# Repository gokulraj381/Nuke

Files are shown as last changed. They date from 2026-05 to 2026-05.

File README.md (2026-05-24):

# 🌱 Plant Buddy — Automated Plant Watering Bot

> A DIY automated plant watering system using ESP32-C3 SuperMini.  
> Monitors soil moisture, waters your plant automatically, shows status on OLED, and provides a Wi-Fi web dashboard for control.

**Anyone can build this!** Follow the step-by-step guide below.

---

## What Does It Do?

1. **Reads soil moisture** — sensor tells the ESP32 how dry/wet the soil is.
2. **Auto-waters** — when soil is too dry, the relay turns ON the pump for a short burst.
3. **Shows live data** — OLED screen displays moisture %, pump status, and Wi-Fi IP address.
4. **Web dashboard** — connect your phone to the ESP32's Wi-Fi and control everything from a browser.
5. **Manual button** — press a physical button to water immediately.
6. **Remembers settings** — calibration and thresholds are saved even after power-off.

---

## Project Photos

### Finished Build (3D-Printed Enclosure)
| Front (OLED + Button) | Inside (ESP32-C3 + Wiring) |
|:---:|:---:|
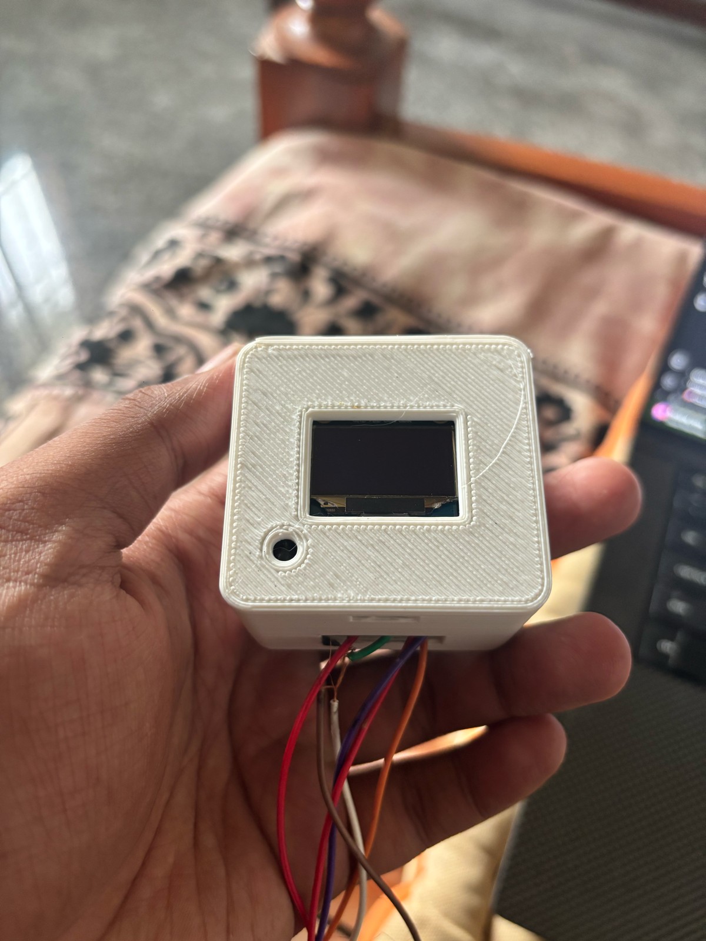
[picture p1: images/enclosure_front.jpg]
Enclosure Front
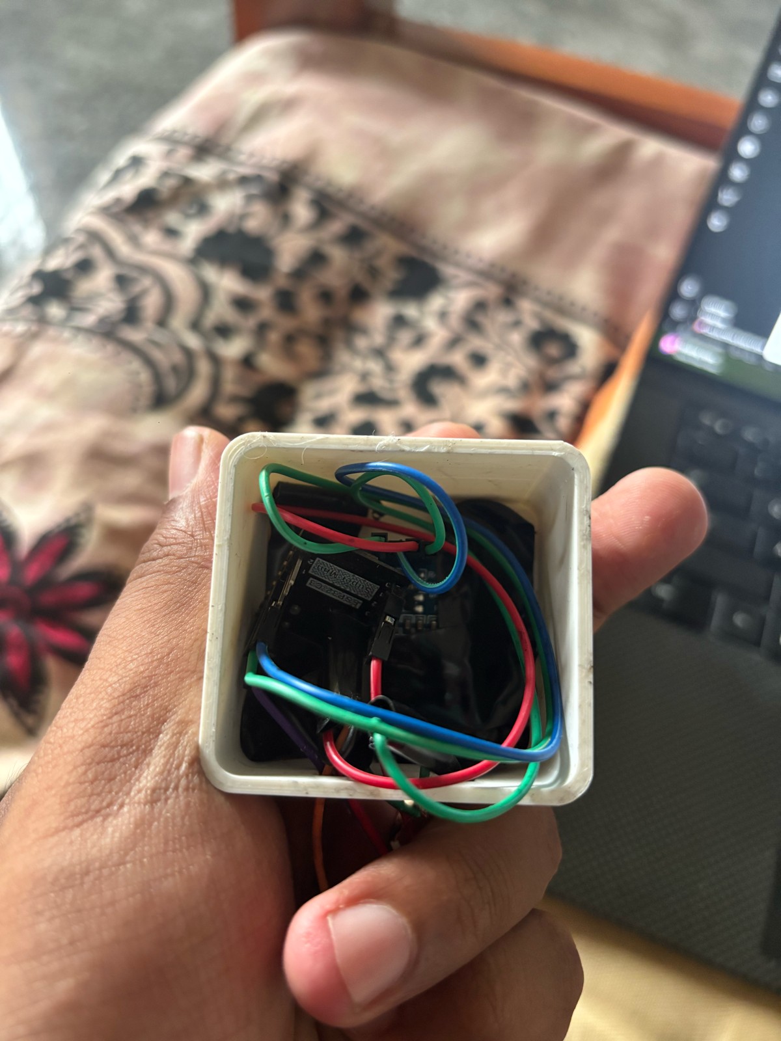
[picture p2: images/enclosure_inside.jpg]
Enclosure Inside
|  |  |

### Component Connections
| OLED Display | Soil Moisture Sensor | Relay Module |
|:---:|:---:|:---:|
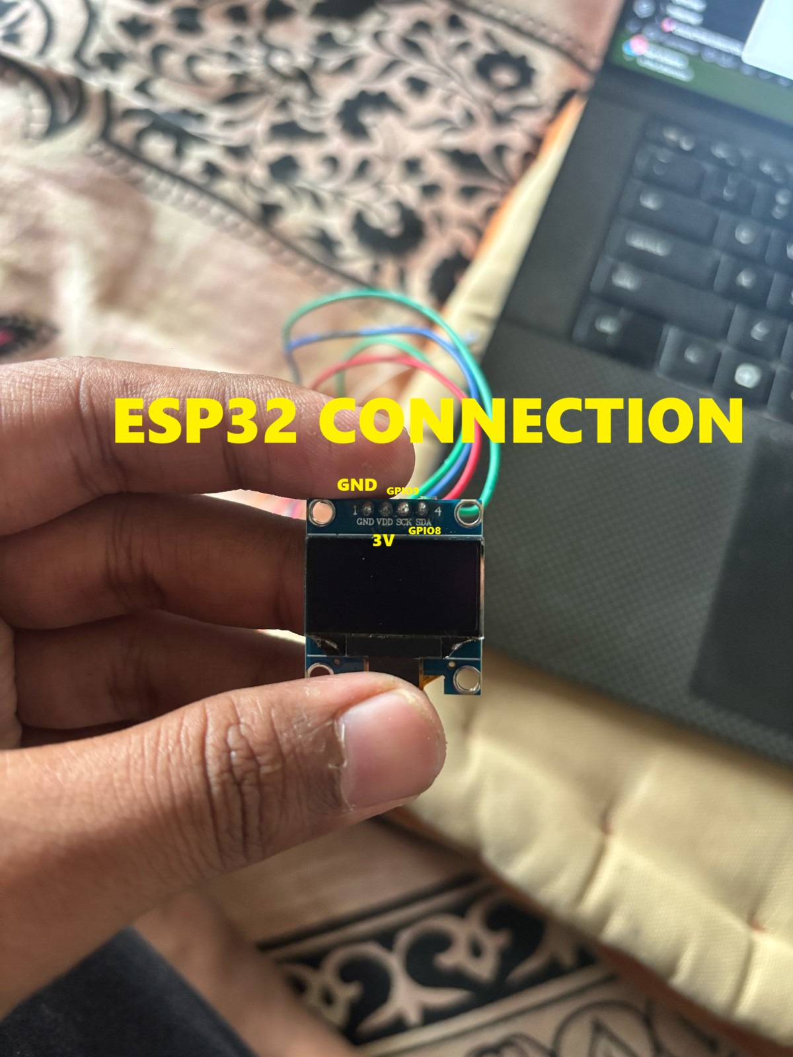
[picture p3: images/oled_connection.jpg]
OLED Connection
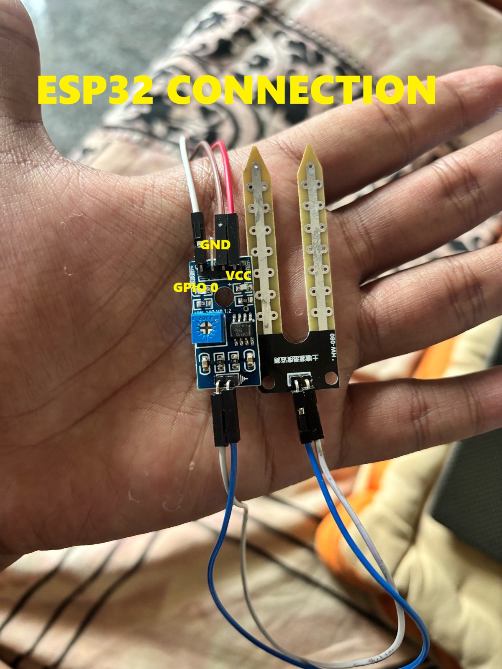
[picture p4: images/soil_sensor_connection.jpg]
Soil Sensor Connection
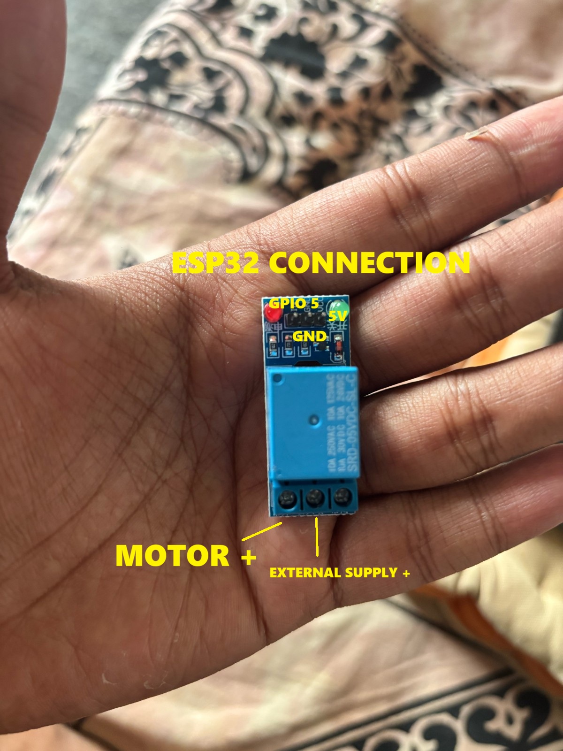
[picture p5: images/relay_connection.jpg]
Relay Connection
|  |  |  |

---

## Step-by-Step Build Guide

### Step 1: Understand the System

```
┌─────────────────────────────────────────────────────────────────────────┐
│                                                                         │
│   [Soil Sensor] ──analog──► [ESP32-C3] ──GPIO5──► [Relay] ──► [Pump]   │
│                                 │                                       │
│                            [OLED Screen]                                │
│                            [Button]                                     │
│                            [Wi-Fi Dashboard]                            │
│                                                                         │
└─────────────────────────────────────────────────────────────────────────┘
```

**How it works:**
- The soil sensor outputs an analog voltage (low = wet, high = dry).
- ESP32 reads it, calculates moisture %, and decides if watering is needed.
- If soil is dry → ESP32 sends LOW signal to relay → relay closes → pump runs.
- OLED + web dashboard show real-time info.

---

### Step 2: Pin Connections (IMPORTANT — Follow Exactly)

#### ESP32-C3 SuperMini Pin Map

| ESP32 Pin | Connects To | Wire Color (suggested) | Purpose |
|---|---|---|---|
| **GPIO0** | Soil sensor AO (analog out) | Blue | Read moisture level |
| **GPIO4** | Push button (other leg to GND) | Yellow | Manual water trigger |
| **GPIO5** | Relay IN pin | Green | Control pump ON/OFF |
| **GPIO8** | OLED SDA pin | Blue/White | OLED data |
| **GPIO9** | OLED SCL pin | Green/White | OLED clock |
| **3.3V** | OLED VCC + Soil sensor VCC | Red | Power to sensors |
| **5V** | Relay VCC | Red | Power to relay module |
| **GND** | OLED GND + Sensor GND + Relay GND + Button | Black | Common ground |

---

### Step 3: Wire the OLED Display

```
OLED Module          ESP32-C3 SuperMini
──────────           ──────────────────
   GND   ──────────►  GND
   VCC   ──────────►  3.3V  (or 3V pin)
   SCL   ──────────►  GPIO9
   SDA   ──────────►  GPIO8
```

> **Tip:** The OLED has 4 pins. Match GND-VCC-SCL-SDA carefully. Wrong VCC/GND will NOT damage it but nothing will display.

---

### Step 4: Wire the Soil Moisture Sensor

```
Soil Sensor Board    ESP32-C3 SuperMini
─────────────────    ──────────────────
   GND   ──────────►  GND
   VCC   ──────────►  3.3V
   AO    ──────────►  GPIO0  (analog output)
```

> **Note:** Use the **AO** (analog) pin, NOT the DO (digital) pin.  
> The sensor also has a separate 2-pin connector going to the fork probes — just plug that in.

---

### Step 5: Wire the Relay Module (Controls the Pump)

```
Relay Module         ESP32-C3 SuperMini
────────────         ──────────────────
   IN    ──────────►  GPIO5
   GND   ──────────►  GND
   VCC   ──────────►  5V

Relay Screw Terminals (high-voltage side):
   COM   ──────────►  Pump (+) wire
   NO    ──────────►  External 5V supply (+)

Pump (-) wire ──────► External 5V supply GND
                      External supply GND ──► ESP32 GND (MUST share ground)
```

**How the relay works:**
- When GPIO5 = HIGH → Relay OFF → Pump stops
- When GPIO5 = LOW → Relay ON → Pump runs
- The relay acts as a switch between your pump and the 5V power supply

> ⚠️ **NEVER** connect the pump directly to ESP32 pins. The pump draws too much current and will kill the chip.

---

### Step 6: Wire the Manual Button

```
Push Button          ESP32-C3 SuperMini
───────────          ──────────────────
   Leg 1  ──────────►  GPIO4
   Leg 2  ──────────►  GND
```

> **That's it!** The firmware uses internal pull-up. When you press the button, it connects GPIO4 to GND, which triggers a manual watering cycle.

---

### Step 7: Power Everything

**Option A: Single USB cable (recommended for testing)**
- Plug USB-C into the ESP32-C3 SuperMini
- This powers the ESP32 + OLED + Sensor
- For the pump, you need a separate 5V supply to the relay screw terminals

**Option B: External 5V supply powers everything**
- Feed 5V to ESP32's 5V pin and to relay/pump
- Share GND across all components

> ⚠️ **The pump MUST have its own 5V supply.** Don't try to run the pump from the ESP32 USB port — it can't provide enough current.

---

### Step 8: Upload the Firmware

#### Prerequisites
1. Install [VS Code](https://code.visualstudio.com/)
2. Install the **PlatformIO** extension (search "PlatformIO IDE" in Extensions)

#### Upload Steps
1. Open this project folder in VS Code
2. Connect ESP32-C3 SuperMini via USB-C cable
3. Wait for PlatformIO to install dependencies (first time takes a minute)
4. Click the **→ (Upload)** button in the PlatformIO toolbar at the bottom
   - Or run in terminal: `pio run -t upload`
5. Click the **🔌 (Serial Monitor)** button to see output at 115200 baud

**If upload fails:**
- Hold the BOOT button on ESP32 while clicking Upload
- Make sure the USB cable supports data (some are charge-only)
- Install CP2102/CH340 USB drivers if your OS doesn't detect the board

---

### Step 9: Connect to the Dashboard

1. After upload, the OLED will show the device IP address
2. On your phone/laptop, connect to Wi-Fi:
   - **SSID:** `PlantBuddy-C3`
   - **Password:** `plantbuddy123`
3. Open a browser and go to the IP shown on OLED (usually `192.168.4.1`)
4. You'll see the web dashboard with live moisture data and controls

> **Optional:** To connect to your home Wi-Fi instead of AP mode, edit these lines in `src/main.cpp`:
> ```cpp
> static const char* WIFI_SSID = "YourWiFiName";
> static const char* WIFI_PASSWORD = "YourWiFiPassword";
> ```

---

### Step 10: Calibrate the Sensor (MUST DO)

Every soil sensor is slightly different. You need to tell the system what "dry" and "wet" look like for YOUR sensor.

1. Open the web dashboard
2. **Keep the sensor probe in AIR (completely dry)**
   - Click **"Set Dry"** button on dashboard
   - This saves the current ADC reading as the "dry" reference
3. **Put the sensor probe fully into WATER (or very wet soil)**
   - Click **"Set Wet"** button on dashboard
   - This saves the current ADC reading as the "wet" reference
4. Set your preferred thresholds:
   - **Low threshold** (default 35%) — pump starts when moisture drops below this
   - **Target threshold** (default 55%) — pump stops when moisture rises above this
5. Click **"Save Settings"** — values are stored permanently

---

## System Block Diagram (Detailed)

```
                         ┌──────────────────────────────────┐
                         │      ESP32-C3 SuperMini          │
                         │                                  │
   ┌─────────────┐      │  GPIO8 (SDA) ◄──── I2C ────►    │      ┌──────────────────┐
   │  1.3" OLED  │◄────►│  GPIO9 (SCL)                    │      │  Soil Moisture   │
   │  (SSD1306)  │      │                                  │◄─────│  Sensor (AO)     │
   │  128x64 I2C │      │  GPIO0 (ADC) ◄── Analog In      │      │  Analog Output   │
   └─────────────┘      │                                  │      └──────────────────┘
                         │  GPIO5 (OUT) ──► Relay IN         │
                         │                      │           │      ┌──────────────────┐
                         │                      ▼           │      │   5V Water Pump  │
                         │               ┌───────────┐      │      │                  │
                         │               │   RELAY   │──────┼─────►│  (via NO/COM)    │
                         │               └───────────┘      │      └──────────────────┘
                         │                                  │
   ┌─────────────┐      │  GPIO4 (IN_PULLUP) ◄── Button   │      ┌──────────────────┐
   │ Push Button │──────►│                                  │      │  External 5V PSU │
   │ (Manual)    │      │  GPIO1 (IN_PULLUP) ◄── Tank Sw  │──────│  (Pump Power)    │
   └─────────────┘      │                                  │      └──────────────────┘
                         │  Wi-Fi (AP/STA)                  │
   ┌─────────────┐      │      ▲                           │
   │  Phone/PC   │◄────►│      │ HTTP Web Dashboard        │
   │  Browser    │      │                                  │
   └─────────────┘      └──────────────────────────────────┘
```

---

## Dashboard Controls Explained

| Button | What It Does |
|---|---|
| **Water Now** | Immediately turns on pump for a short burst (manual watering) |
| **Toggle Auto** | Enable/disable automatic watering logic |
| **Set Dry** | Save current ADC reading as the "dry soil" calibration point |
| **Set Wet** | Save current ADC reading as the "wet soil" calibration point |
| **Save Settings** | Write all values to flash memory (survives reboot/power-off) |

**Live display shows:** Moisture %, raw ADC value, pump ON/OFF status, tank level (if connected)

---

## Settings Reference

| Setting | What It Means | Default |
|---|---|---|
| Dry ADC | ADC reading when sensor is in dry air | 4005 |
| Wet ADC | ADC reading when sensor is in water | 1921 |
| Low Threshold | Start watering when moisture drops below this % | 35% |
| Target Threshold | Stop watering when moisture rises above this % | 55% |
| Pump Run Time | How long pump runs per auto-water cycle | 700 ms |
| Cooldown | Minimum wait between auto-water cycles | 90 seconds |
| Manual Pump Time | How long pump runs when you press the button | 600 ms |

---

## Troubleshooting

| Problem | Solution |
|---|---|
| OLED blank | Check SDA/SCL wires. Try swapping them. Ensure OLED address is 0x3C |
| Moisture always 0% or 100% | Run calibration (Set Dry + Set Wet). Check AO wire to GPIO0 |
| Pump won't turn on | Check relay wiring. Ensure external 5V supply is connected. Check COM/NO terminals |
| Can't upload firmware | Hold BOOT button during upload. Try a different USB cable |
| Can't find Wi-Fi | Wait 10 seconds after power-on. SSID is `PlantBuddy-C3` |
| Dashboard not loading | Make sure you're connected to PlantBuddy Wi-Fi, then open `192.168.4.1` |
| Pump runs non-stop | Calibration is wrong — redo Set Dry / Set Wet. Check threshold values |

---

## Project Structure

```
plant-buddy/
├── platformio.ini              # Build config + library dependencies
├── README.md                   # This guide
├── images/                     # Photos of the build
├── cad/                        # 3D-printable enclosure files
│   ├── plantbuddy_back.scad    # Back cover (OpenSCAD source)
│   ├── plantbuddy_front.scad   # Front panel with OLED cutout
│   └── stl/                    # Ready-to-print STL files
└── src/
    └── main.cpp                # Complete firmware (single file)
```

---

## Optional: 3D-Printed Case

STL files are in the `cad/stl/` folder. Print with:
- Material: PLA or PETG
- Layer height: 0.2mm
- Infill: 20%
- No supports needed

The case has a cutout for the OLED display and a hole for the manual button.

---

## Optional: Tank Level Switch

If you want the system to stop watering when the water tank is empty:

1. In `src/main.cpp`, change: `static const bool USE_TANK_SENSOR = true;`
2. Connect a float switch between **GPIO1** and **GND**
3. When tank is empty, the switch opens → GPIO1 reads HIGH → pump won't run

---

## License

MIT — Free to use, modify, and share.

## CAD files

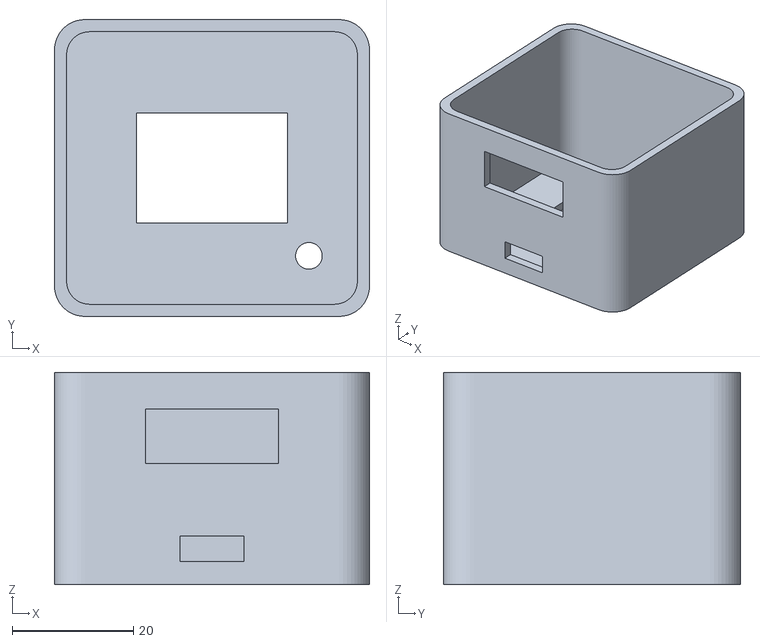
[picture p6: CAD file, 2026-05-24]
cad/stl/plantbuddy_front.stl
52.0 x 49.0 x 35.0

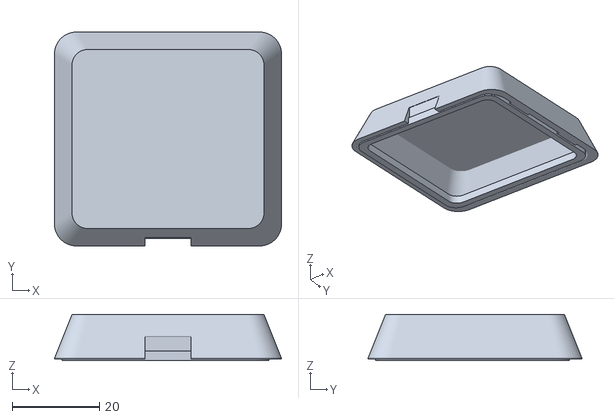
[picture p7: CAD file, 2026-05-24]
cad/stl/plantbuddy_back.stl
52.0 x 49.0 x 10.6

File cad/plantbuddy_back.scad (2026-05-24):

// Plant Buddy - Back Shell
// Nico-style rounded dome back with snap lip, vent slots, and cable exit.

$fn = 48;

wall = 2.0;
corner_r = 5;
lip_h = 2.2;
lip_inset = 0.30;
lip_shell_overlap_z = -0.4;
lip_shell_overlap_xy = 0.55;
eps = 0.2;

inner_w = 48.0;
inner_h = 45.0;

ext_w = inner_w + wall * 2;
ext_h = inner_h + wall * 2;

dome_h = 10.0;

usb_w = 10.5;
usb_h = 4.2;

module rounded_box(w, h, d, r) {
    hull() {
        for (x = [r, w - r])
            for (y = [r, h - r])
                translate([x, y, 0])
                    cylinder(r = r, h = d);
    }
}

module dome_back(w, h, rise) {
    hull() {
        rounded_box(w, h, 0.15, corner_r);
        translate([4, 4, rise])
            rounded_box(w - 8, h - 8, 0.15, corner_r - 1.4);
    }
}

difference() {
    // Outer skin.
    dome_back(ext_w, ext_h, dome_h);

    // Hollow interior shell.
    translate([wall, wall, -eps])
        dome_back(ext_w - wall * 2, ext_h - wall * 2, dome_h - wall + eps);

    // USB opening alignment.
    translate([ext_w / 2 - usb_w / 2, -0.1, -0.1])
        cube([usb_w, wall + 0.2, usb_h + 1.0]);

    // Ventilation slots near top.
    for (i = [0:4])
        translate([ext_w / 2 - 10 + i * 5, ext_h - wall - 0.1, dome_h - 2])
            rotate([-90, 0, 0])
                cylinder(r = 1.0, h = wall + 0.2);
}

// Snap-fit lip that goes inside the front shell.
translate([wall + lip_inset - lip_shell_overlap_xy, wall + lip_inset - lip_shell_overlap_xy, lip_shell_overlap_z])
difference() {
    rounded_box(inner_w - lip_inset * 2, inner_h - lip_inset * 2, lip_h, corner_r - 1.5);
    translate([wall, wall, -0.1])
        rounded_box(inner_w - lip_inset * 2 - wall * 2, inner_h - lip_inset * 2 - wall * 2, lip_h + 0.2, corner_r - 2.3);
}

// Bridge tabs that tie the lip to shell rim (prevents multi-volume STL export).
translate([wall - 0.2, wall + 8, 0]) cube([0.9, 8, 1.8]);
translate([wall - 0.2, ext_h - wall - 16, 0]) cube([0.9, 8, 1.8]);
translate([ext_w - wall - 0.7, wall + 8, 0]) cube([0.9, 8, 1.8]);
translate([ext_w - wall - 0.7, ext_h - wall - 16, 0]) cube([0.9, 8, 1.8]);

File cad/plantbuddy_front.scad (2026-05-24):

// Plant Buddy - Front Shell
// Nico-style rounded shell with two leaf ears, OLED window, and button hole.

$fn = 48;

// Core dimensions (mm)
wall = 2.0;
tol = 0.35;
corner_r = 5;

oled_module_w = 26.0;   // 2.6 cm OLED module width
oled_module_h = 30.0;   // 3.0 cm OLED module height
display_total_h = oled_module_h;
oled_glass_w = 25.0;    // 2.5 cm window width
oled_glass_h = 17.0;    // 1.7 cm window height

inner_w = 48.0;
inner_h = 45.0;
front_total_depth = 35.0; // 3.5 cm front-only depth (front to back)
inner_d = front_total_depth - wall;

ext_w = inner_w + wall * 2;
ext_h = inner_h + wall * 2;
ext_d = inner_d + wall;

usb_w = 10.5;
usb_h = 4.2;

button_r = 2.2;
eps = 0.2;

module rounded_box(w, h, d, r) {
    hull() {
        for (x = [r, w - r])
            for (y = [r, h - r])
                translate([x, y, 0])
                    cylinder(r = r, h = d);
    }
}

module leaf_ear(height, base_w, tip_shift, depth) {
    translate([0, 0, -depth / 2])
    linear_extrude(height = depth) {
        // Leaf silhouette kept solid to avoid split volumes.
        hull() {
            scale([1.0, 0.50]) circle(r = base_w / 2);
            translate([tip_shift * 0.45, height * 0.55])
                scale([0.75, 0.35]) circle(r = base_w / 2);
            translate([tip_shift, height])
                circle(r = 2.2);
        }
    }
}

difference() {
    union() {
        rounded_box(ext_w, ext_h, ext_d, corner_r);
    }

    // Main internal cavity.
    translate([wall, wall, wall - eps])
        rounded_box(inner_w, inner_h, ext_d + eps * 2, corner_r - 1.2);

    // OLED viewing window.
    oled_win_w = oled_glass_w;
    oled_win_h = oled_glass_h + 1.2;
    win_x = (ext_w - oled_win_w) / 2;
    win_y = (ext_h - display_total_h) / 2 + (display_total_h - oled_win_h) / 2;
    translate([win_x, win_y, -0.1])
        cube([oled_win_w, oled_win_h, wall + 0.2]);

    // USB-C opening (bottom edge).
    translate([ext_w / 2 - usb_w / 2, -0.1, wall + 1.8])
        cube([usb_w, wall + 0.2, usb_h]);

    // Right-side near-back wire hole (away from OLED side), support-free profile.
    right_back_hole_w = 21.0;
    right_back_hole_h = 6.0;
    right_back_hole_cy = ext_h - 12.0;
    right_back_hole_cz = ext_d - (wall + 4.2);
    translate([ext_w - 0.1, 0, 0])
        linear_extrude(height = wall + 0.2)
            polygon(points = [
                [right_back_hole_cy - right_back_hole_w / 2, right_back_hole_cz],
                [right_back_hole_cy, right_back_hole_cz + right_back_hole_h / 2],
                [right_back_hole_cy + right_back_hole_w / 2, right_back_hole_cz],
                [right_back_hole_cy, right_back_hole_cz - right_back_hole_h / 2]
            ]);

    // Large rectangular hole at marked front area (upper center of visible side).
    front_marked_hole_w = 22.0;
    front_marked_hole_h = 9.0;
    front_marked_hole_x = (ext_w - front_marked_hole_w) / 2;
    front_marked_hole_z = ext_d - 15.0;
    translate([front_marked_hole_x, -0.1, front_marked_hole_z])
        cube([front_marked_hole_w, wall + 0.2, front_marked_hole_h]);

    // Manual button hole near lower-right front.
    translate([ext_w - 10, 10, -0.1])
        cylinder(r = button_r, h = wall + 0.2);

}

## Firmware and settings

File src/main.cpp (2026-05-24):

#include <Arduino.h>
#include <Wire.h>
#include <Adafruit_GFX.h>
#include <Adafruit_SSD1306.h>
#include <WiFi.h>
#include <WebServer.h>
#include <Preferences.h>
#include <time.h>

// -------- OLED CONFIG --------
static const int SCREEN_WIDTH = 128;
static const int SCREEN_HEIGHT = 64;
static const int OLED_RESET = -1;
static const uint8_t OLED_ADDR = 0x3C;

// ESP32-C3 SuperMini common I2C pins (change if your board uses others)
static const int I2C_SDA_PIN = 8;
static const int I2C_SCL_PIN = 9;

// -------- PLANT SYSTEM PINS --------
// Moisture sensor analog output pin (ADC-capable). GPIO0 is common on ESP32-C3.
static const int SOIL_SENSOR_PIN = 0;

// Pump control pin. Drive a MOSFET/relay, never the pump directly.
static const int PUMP_PIN = 5;
static const bool RELAY_ACTIVE_LOW = true;

// Manual force-water button (connect button to GND and this pin).
static const int MANUAL_BUTTON_PIN = 4;

// Optional tank level switch (set to false if you do not use one).
static const bool USE_TANK_SENSOR = false;
static const int TANK_SENSOR_PIN = 1;

// -------- WIFI CONFIG --------
// Leave WIFI_SSID empty to run AP-only mode.
static const char* WIFI_SSID = "";
static const char* WIFI_PASSWORD = "";
static const char* AP_SSID = "PlantBuddy-C3";
static const char* AP_PASSWORD = "plantbuddy123";

// -------- CALIBRATION (TUNE THESE) --------
// Raw ADC value when probe is in DRY soil
static int sensorDry = 4005;
// Raw ADC value when probe is in WET soil
static int sensorWet = 1921;

// Watering behavior
static int moistureLowThreshold = 35;
static int moistureTargetAfterWater = 55;
static unsigned long pumpRunMs = 700;
static unsigned long pumpCooldownMs = 90000;
static unsigned long manualPumpMs = 600;
static bool autoWaterEnabled = true;

// Sampling and display
static const unsigned long SENSOR_SAMPLE_MS = 2000;
static const unsigned long DISPLAY_REFRESH_MS = 120;

static const unsigned long BUTTON_DEBOUNCE_MS = 60;

Adafruit_SSD1306 display(SCREEN_WIDTH, SCREEN_HEIGHT, &Wire, OLED_RESET);
uint8_t oledAddrDetected = OLED_ADDR;
WebServer server(80);
Preferences prefs;

unsigned long lastSampleMs = 0;
unsigned long lastDisplayMs = 0;
unsigned long pumpStartedMs = 0;
unsigned long lastWateringMs = 0;
unsigned long lastButtonChangeMs = 0;

bool pumpIsOn = false;
bool pumpManualMode = false;
bool buttonState = HIGH;
bool lastButtonState = HIGH;
bool tankLow = false;

int rawReading = 0;
int moisturePct = 0;
bool moistureSensorConnected = true;
uint8_t moistureValidStreak = 0;
uint8_t moistureInvalidStreak = 0;
int moistureHistory[5] = {0, 0, 0, 0, 0};
uint8_t moistureHistoryCount = 0;
uint8_t moistureHistoryIndex = 0;
String wifiIp = "0.0.0.0";
unsigned long sunflowerAnimStartMs = 0;
static const bool USE_BACKUP_ANIMATION = false;
String wateredDaysCsv = "";
String lastWateredAt = "Never";
String lastWateringMode = "-";
unsigned long waterEvents = 0;

int clampInt(int value, int lo, int hi) {
  if (value < lo) return lo;
  if (value > hi) return hi;
  return value;
}

int pumpOutputLevel(bool on) {
  if (RELAY_ACTIVE_LOW) {
    return on ? LOW : HIGH;
  }
  return on ? HIGH : LOW;
}

unsigned long clampULong(unsigned long value, unsigned long lo, unsigned long hi) {
  if (value < lo) return lo;
  if (value > hi) return hi;
  return value;
}

String uptimeStamp() {
  unsigned long totalMin = millis() / 60000UL;
  unsigned long hours = totalMin / 60UL;
  unsigned long minutes = totalMin % 60UL;
  return String("Uptime ") + String(hours) + "h " + String(minutes) + "m";
}

bool hasValidClock() {
  return time(nullptr) > 1700000000;
}

String currentDayStamp() {
  if (!hasValidClock()) {
    return String("Session-Day-") + String((millis() / 86400000UL) + 1UL);
  }

  time_t now = time(nullptr);
  struct tm t;
  localtime_r(&now, &t);
  char buff[16];
  strftime(buff, sizeof(buff), "%Y-%m-%d", &t);
  return String(buff);
}

String currentDateTimeStamp() {
  if (!hasValidClock()) {
    return uptimeStamp();
  }

  time_t now = time(nullptr);
  struct tm t;
  localtime_r(&now, &t);
  char buff[24];
  strftime(buff, sizeof(buff), "%Y-%m-%d %H:%M", &t);
  return String(buff);
}

bool csvContainsToken(const String& csv, const String& token) {
  if (csv.length() == 0 || token.length() == 0) return false;

  int start = 0;
  while (start <= csv.length()) {
    int comma = csv.indexOf(',', start);
    if (comma < 0) comma = csv.length();
    String piece = csv.substring(start, comma);
    piece.trim();
    if (piece == token) return true;
    if (comma >= csv.length()) break;
    start = comma + 1;
  }
  return false;
}

void trimWateredDaysToMax(int maxDays) {
  if (maxDays < 1) return;

  int tokens = 0;
  for (int i = 0; i < wateredDaysCsv.length(); i++) {
    if (wateredDaysCsv[i] == ',') tokens++;
  }
  if (wateredDaysCsv.length() > 0) tokens++;

  while (tokens > maxDays) {
    int comma = wateredDaysCsv.indexOf(',');
    if (comma < 0) {
      wateredDaysCsv = "";
      break;
    }
    wateredDaysCsv = wateredDaysCsv.substring(comma + 1);
    tokens--;
  }
}

void saveWaterHistory() {
  prefs.begin("plant", false);
  prefs.putString("waterDays", wateredDaysCsv);
  prefs.putString("lastWAt", lastWateredAt);
  prefs.putString("lastWMode", lastWateringMode);
  prefs.putULong("waterCnt", waterEvents);
  prefs.end();
}

void recordWateringEvent(const char* mode) {
  String day = currentDayStamp();
  if (!csvContainsToken(wateredDaysCsv, day)) {
    if (wateredDaysCsv.length() > 0) wateredDaysCsv += ",";
    wateredDaysCsv += day;
    trimWateredDaysToMax(20);
  }

  waterEvents++;
  lastWateredAt = currentDateTimeStamp();
  lastWateringMode = String(mode);
  saveWaterHistory();
}

bool canWaterNow() {
  if (!USE_TANK_SENSOR) return true;
  return !tankLow;
}

void loadSettings() {
  prefs.begin("plant", true);
  sensorDry = prefs.getInt("sensorDry", sensorDry);
  sensorWet = prefs.getInt("sensorWet", sensorWet);
  moistureLowThreshold = prefs.getInt("lowThr", moistureLowThreshold);
  moistureTargetAfterWater = prefs.getInt("targetThr", moistureTargetAfterWater);
  pumpRunMs = prefs.getULong("pumpRun", pumpRunMs);
  pumpCooldownMs = prefs.getULong("cooldown", pumpCooldownMs);
  manualPumpMs = prefs.getULong("manualRun", manualPumpMs);
  autoWaterEnabled = prefs.getBool("autoOn", autoWaterEnabled);
  wateredDaysCsv = prefs.getString("waterDays", wateredDaysCsv);
  lastWateredAt = prefs.getString("lastWAt", lastWateredAt);
  lastWateringMode = prefs.getString("lastWMode", lastWateringMode);
  waterEvents = prefs.getULong("waterCnt", waterEvents);
  prefs.end();

  moistureLowThreshold = clampInt(moistureLowThreshold, 5, 95);
  moistureTargetAfterWater = clampInt(moistureTargetAfterWater, moistureLowThreshold + 1, 100);
  sensorDry = clampInt(sensorDry, 0, 4095);
  sensorWet = clampInt(sensorWet, 0, 4095);
  pumpRunMs = clampULong(pumpRunMs, 200, 30000);
  pumpCooldownMs = clampULong(pumpCooldownMs, 5000, 600000);
  manualPumpMs = clampULong(manualPumpMs, 200, 30000);
  trimWateredDaysToMax(20);
}

void saveSettings() {
  prefs.begin("plant", false);
  prefs.putInt("sensorDry", sensorDry);
  prefs.putInt("sensorWet", sensorWet);
  prefs.putInt("lowThr", moistureLowThreshold);
  prefs.putInt("targetThr", moistureTargetAfterWater);
  prefs.putULong("pumpRun", pumpRunMs);
  prefs.putULong("cooldown", pumpCooldownMs);
  prefs.putULong("manualRun", manualPumpMs);
  prefs.putBool("autoOn", autoWaterEnabled);
  prefs.end();
}

int readMoisturePercent() {
  rawReading = analogRead(SOIL_SENSOR_PIN);

  // Store recent samples to detect floating/disconnected behavior.
  moistureHistory[moistureHistoryIndex] = rawReading;
  moistureHistoryIndex = (moistureHistoryIndex + 1) % 5;
  if (moistureHistoryCount < 5) moistureHistoryCount++;

  int minRaw = 4095;
  int maxRaw = 0;
  int railCount = 0;
  for (uint8_t i = 0; i < moistureHistoryCount; i++) {
    int v = moistureHistory[i];
    if (v < minRaw) minRaw = v;
    if (v > maxRaw) maxRaw = v;
    if (v <= 40 || v >= 4055) railCount++;
  }

  int span = maxRaw - minRaw;
  bool railInvalid = (rawReading <= 20 || rawReading >= 4075);
  bool unstableInvalid = (moistureHistoryCount >= 3) && (span > 700);
  bool historyInvalid = (moistureHistoryCount >= 3) && (railCount > 0);
  bool sampleLooksDisconnected = railInvalid || unstableInvalid || historyInvalid;

  // Hysteresis: require repeated evidence before toggling connected state.
  if (sampleLooksDisconnected) {
    moistureInvalidStreak = (moistureInvalidStreak < 255) ? (moistureInvalidStreak + 1) : 255;
    moistureValidStreak = 0;
  } else {
    moistureValidStreak = (moistureValidStreak < 255) ? (moistureValidStreak + 1) : 255;
    moistureInvalidStreak = 0;
  }

  if (moistureInvalidStreak >= 2) moistureSensorConnected = false;
  if (moistureValidStreak >= 3) moistureSensorConnected = true;

  if (!moistureSensorConnected) {
    moisturePct = 0;

    if (USE_TANK_SENSOR) {
      // LOW means tank is empty when using INPUT_PULLUP + float switch to GND.
      tankLow = (digitalRead(TANK_SENSOR_PIN) == LOW);
    }
    return moisturePct;
  }

  // Convert raw ADC to percent where 0 = dry and 100 = wet.
  int pct = map(rawReading, sensorDry, sensorWet, 0, 100);
  moisturePct = clampInt(pct, 0, 100);

  if (USE_TANK_SENSOR) {
    // LOW means tank is empty when using INPUT_PULLUP + float switch to GND.
    tankLow = (digitalRead(TANK_SENSOR_PIN) == LOW);
  }

  return moisturePct;
}

void setPump(bool on) {
  bool wasOn = pumpIsOn;
  pumpIsOn = on;
  digitalWrite(PUMP_PIN, pumpOutputLevel(on));
  if (on && !wasOn) {
    pumpStartedMs = millis();
    lastWateringMs = pumpStartedMs;
    recordWateringEvent(pumpManualMode ? "manual" : "auto");
  }
}

void maybeStartAutoWatering() {
  if (!autoWaterEnabled) return;
  if (pumpIsOn) return;
  if (!moistureSensorConnected) return;
  if (!canWaterNow()) return;

  unsigned long now = millis();
  if (now - lastWateringMs < pumpCooldownMs) return;

  if (moisturePct < moistureLowThreshold) {
    pumpManualMode = false;
    setPump(true);
    Serial.println("[AUTO] Moisture low. Starting watering cycle.");
  }
}

void startManualWatering() {
  if (pumpIsOn) return;
  if (!canWaterNow()) {
    Serial.println("[MANUAL] Watering blocked. Tank appears empty.");
    return;
  }

  pumpManualMode = true;
  setPump(true);
  Serial.println("[MANUAL] Manual watering started.");
}

void maybeStopPump() {
  if (!pumpIsOn) return;

  unsigned long now = millis();
  unsigned long activeRunMs = pumpManualMode ? manualPumpMs : pumpRunMs;
  bool timeReached = (now - pumpStartedMs) >= activeRunMs;

  // Stop early if target moisture reached.
  bool moistureRecovered = moisturePct >= moistureTargetAfterWater;
  if (pumpManualMode) {
    moistureRecovered = false;
  }

  if (timeReached || moistureRecovered) {
    setPump(false);
    pumpManualMode = false;
    Serial.println("[AUTO] Stopping pump.");
  }
}

void handleManualButton() {
  bool current = digitalRead(MANUAL_BUTTON_PIN);
  unsigned long now = millis();

  if (current != lastButtonState) {
    lastButtonChangeMs = now;
    lastButtonState = current;
  }

  if ((now - lastButtonChangeMs) > BUTTON_DEBOUNCE_MS && current != buttonState) {
    buttonState = current;
    if (buttonState == LOW) {
      startManualWatering();
    }
  }
}

void startWifi() {
  WiFi.mode(WIFI_AP_STA);

  bool startedSta = false;
  if (strlen(WIFI_SSID) > 0) {
    WiFi.begin(WIFI_SSID, WIFI_PASSWORD);
    unsigned long startMs = millis();
    while (WiFi.status() != WL_CONNECTED && (millis() - startMs) < 10000) {
      delay(250);
    }
    startedSta = (WiFi.status() == WL_CONNECTED);
  }

  bool startedAp = WiFi.softAP(AP_SSID, AP_PASSWORD);

  if (startedSta) {
    wifiIp = WiFi.localIP().toString();
    configTime(0, 0, "pool.ntp.org", "time.nist.gov");
    Serial.print("[WIFI] STA connected, IP: ");
    Serial.println(wifiIp);
  } else if (startedAp) {
    wifiIp = WiFi.softAPIP().toString();
    Serial.print("[WIFI] AP ready, IP: ");
    Serial.println(wifiIp);
    Serial.print("[WIFI] AP SSID: ");
    Serial.println(AP_SSID);
  } else {
    wifiIp = "0.0.0.0";
    Serial.println("[WIFI] Failed to start Wi-Fi.");
  }
}

String statusJson() {
  String out = "{";
  out += "\"moisture\":" + String(moisturePct) + ",";
  out += "\"sensorConnected\":" + String(moistureSensorConnected ? "true" : "false") + ",";
  out += "\"raw\":" + String(rawReading) + ",";
  out += "\"pumpOn\":" + String(pumpIsOn ? "true" : "false") + ",";
  out += "\"manualMode\":" + String(pumpManualMode ? "true" : "false") + ",";
  out += "\"autoWater\":" + String(autoWaterEnabled ? "true" : "false") + ",";
  out += "\"lowThreshold\":" + String(moistureLowThreshold) + ",";
  out += "\"targetThreshold\":" + String(moistureTargetAfterWater) + ",";
  out += "\"pumpRunMs\":" + String((unsigned long)pumpRunMs) + ",";
  out += "\"cooldownMs\":" + String((unsigned long)pumpCooldownMs) + ",";
  out += "\"manualRunMs\":" + String((unsigned long)manualPumpMs) + ",";
  out += "\"sensorDry\":" + String(sensorDry) + ",";
  out += "\"sensorWet\":" + String(sensorWet) + ",";
  out += "\"tankLow\":" + String(tankLow ? "true" : "false") + ",";
  out += "\"waterEvents\":" + String((unsigned long)waterEvents) + ",";
  out += "\"waterDays\":\"" + wateredDaysCsv + "\",";
  out += "\"lastWateredAt\":\"" + lastWateredAt + "\",";
  out += "\"lastWateringMode\":\"" + lastWateringMode + "\",";
  out += "\"ip\":\"" + wifiIp + "\"";
  out += "}";
  return out;
}

void serveDashboard() {
  static const char* PAGE = R"HTML(
<!doctype html>
<html lang="en">
<head>
  <meta charset="utf-8">
  <meta name="viewport" content="width=device-width, initial-scale=1">
  <title>Plant Buddy C3</title>
  <style>
    :root{--bg:#eef3ea;--ink:#1f2b20;--muted:#5b6d5e;--panel:#fffefb;--line:#d6e1d1;--mint:#6ec49f;--leaf:#2f8b68;--earth:#a36a3e;--danger:#c45050;--ok:#2a8f64}
    *{box-sizing:border-box}
    body{margin:0;min-height:100vh;font-family:'Trebuchet MS','Gill Sans','Segoe UI Variable',sans-serif;color:var(--ink);background:radial-gradient(1000px 520px at -12% -18%,#9dd9b8 0%,transparent 72%),radial-gradient(950px 500px at 110% -10%,#f3c584 0%,transparent 72%),radial-gradient(800px 420px at 50% 110%,#9fc7e8 0%,transparent 70%),linear-gradient(160deg,#f4f9f0 0%,#eef7ef 45%,#eaf0f8 100%)}
    .wrap{max-width:980px;margin:0 auto;padding:20px 14px 26px}
    .hero{padding:18px 18px 14px;border:1px solid #d3e1d0;border-radius:18px;background:linear-gradient(135deg,rgba(255,255,255,.95),rgba(244,255,248,.88));box-shadow:0 18px 34px rgba(24,54,41,.14)}
    .title{display:flex;align-items:center;justify-content:space-between;gap:8px;flex-wrap:wrap}
    h1{margin:0;font-size:1.65rem;letter-spacing:.4px}
    .sub{margin-top:6px;color:var(--muted);font-size:.95rem}
    .badge{display:inline-flex;align-items:center;gap:8px;padding:8px 12px;border-radius:999px;background:linear-gradient(120deg,#e8fff4,#f3fff9);border:1px solid #bfe8d6;font-size:.86rem}
    .dot{width:10px;height:10px;border-radius:50%;background:var(--ok);box-shadow:0 0 0 0 rgba(42,143,100,.45);animation:pulse 1.8s infinite}
    @keyframes pulse{0%{box-shadow:0 0 0 0 rgba(42,143,100,.45)}70%{box-shadow:0 0 0 11px rgba(42,143,100,0)}100%{box-shadow:0 0 0 0 rgba(42,143,100,0)}}
    .grid{display:grid;grid-template-columns:1.4fr 1fr;gap:14px;margin-top:14px}
    .stack{display:grid;gap:14px}
    .card{padding:14px;border-radius:16px;border:1px solid #d6e2d5;background:linear-gradient(145deg,rgba(255,255,255,.94),rgba(250,255,247,.90));box-shadow:0 12px 24px rgba(32,54,42,.12)}
    .card h2{margin:0;font-size:1.02rem}
    .card-head{display:flex;align-items:center;justify-content:space-between;gap:8px;margin-bottom:10px}
    .tiny-btn{padding:6px 10px;border-radius:9px;border:1px solid #cfe1ce;background:#f2f8f1;color:#35553e;font-size:.75rem;font-weight:700;cursor:pointer}
    .meter{display:grid;grid-template-columns:110px 1fr;gap:12px;align-items:center}
    .ring{width:104px;height:104px;border-radius:50%;background:conic-gradient(var(--mint) calc(var(--pct)*1%),#d8e2f0 0);display:grid;place-items:center;transition:all .35s ease}
    .ring-inner{width:78px;height:78px;border-radius:50%;display:grid;place-items:center;background:#fff;border:1px solid #e1eadf;font-size:1.1rem;font-weight:700}
    .statline{display:flex;justify-content:space-between;gap:8px;padding:8px 0;border-bottom:1px dashed #d8e3d7}
    .statline:last-child{border-bottom:0}
    .k{color:var(--muted)}
    .v{font-weight:700}
    .actions{display:grid;grid-template-columns:repeat(2,minmax(0,1fr));gap:8px}
    button{border:0;border-radius:11px;padding:11px 12px;font-weight:700;cursor:pointer;transition:.18s transform,.18s filter}
    button:hover{transform:translateY(-1px);filter:brightness(1.02)}
    .primary{background:linear-gradient(130deg,var(--leaf),#2f74a9);color:#fff}
    .alt{background:linear-gradient(130deg,#edf7ec,#e8f1fb);color:#284432;border:1px solid #cfe0d4}
    .warn{background:linear-gradient(130deg,var(--earth),#cb7f55);color:#fff}
    .history-days{display:flex;flex-wrap:wrap;gap:6px;min-height:30px}
    .chip{padding:5px 9px;border-radius:999px;background:#eef5ea;border:1px solid #d4e3d2;font-size:.82rem}
    .empty{color:#7b8e80;font-size:.9rem}
    .calendar-head{display:flex;justify-content:space-between;align-items:center;gap:8px;margin:10px 0 6px}
    .calendar-grid{display:grid;grid-template-columns:repeat(7,minmax(0,1fr));gap:6px}
    .cal-dow{font-size:.72rem;color:#607465;text-align:center;padding:2px 0}
    .cal-day{height:30px;border-radius:8px;display:grid;place-items:center;font-size:.78rem;border:1px solid #d6e3d5;background:#f7faf6;color:#324b39}
    .cal-watered{background:#cdebd0;border-color:#9fd7a5;color:#215a2d;font-weight:700}
    .cal-dry{background:#f5d9d9;border-color:#e3b3b3;color:#7e2f2f}
    .cal-future{background:#f2f4f1;border-color:#e3e8e0;color:#9aa89b}
    .demo-row{display:flex;justify-content:space-between;align-items:center;gap:8px;margin-top:10px}
    .switch{position:relative;width:46px;height:26px;display:inline-block}
    .switch input{opacity:0;width:0;height:0}
    .slider{position:absolute;cursor:pointer;inset:0;background:#d1ddd0;transition:.2s;border-radius:999px}
    .slider:before{content:"";position:absolute;height:20px;width:20px;left:3px;top:3px;background:white;transition:.2s;border-radius:50%}
    .switch input:checked + .slider{background:#6ca572}
    .switch input:checked + .slider:before{transform:translateX(20px)}
    .logs{margin-top:10px;max-height:130px;overflow:auto;border:1px dashed #d4e2d2;border-radius:10px;padding:8px;background:#fbfdfb}
    .log-item{font-size:.82rem;color:#35533d;padding:4px 0;border-bottom:1px dotted #d8e4d8}
    .log-item:last-child{border-bottom:0}
    .fields{display:grid;grid-template-columns:repeat(3,minmax(0,1fr));gap:8px}
    label{display:block;margin-bottom:4px;font-size:.8rem;color:#405443}
    input{width:100%;padding:9px;border-radius:10px;border:1px solid #cfe0cd;background:#fff}
    .footer-note{margin-top:10px;font-size:.82rem;color:#6a7f70}
    .focus-hidden{display:none !important}
    .fullscreen-card{position:fixed !important;inset:10px !important;z-index:9999 !important;overflow:auto !important;margin:0 !important;padding:18px !important;border-radius:18px !important;box-shadow:0 30px 50px rgba(24,35,27,.25) !important}
    .focus-exit{position:fixed;right:18px;top:16px;z-index:10000;border:0;border-radius:999px;padding:8px 14px;background:#213225;color:#fff;font-weight:700;cursor:pointer;display:none}
    body.focus-active .focus-exit{display:inline-block}
    @media (max-width:860px){.grid{grid-template-columns:1fr}.fields{grid-template-columns:1fr 1fr}}
    @media (max-width:560px){.fields{grid-template-columns:1fr}.actions{grid-template-columns:1fr}}
  </style>
</head>
<body>
<div class="wrap">
  <section class="hero">
    <div class="title">
      <div>
        <h1>Plant Buddy Dashboard</h1>
        <div class="sub">Live moisture, watering controls, and watering-day history</div>
      </div>
      <div class="badge"><span class="dot"></span><span id="ip">Waiting for device...</span></div>
    </div>
  </section>

  <section class="grid">
    <div class="stack">
      <div class="card focusable-card" id="statusCard">
        <div class="card-head">
          <h2>Live Plant Status</h2>
          <button id="btnStatusFullscreen" class="tiny-btn">Fullscreen</button>
        </div>
        <div class="meter">
          <div class="ring" id="ring" style="--pct:0"><div class="ring-inner"><span id="mo">--%</span></div></div>
          <div>
            <div class="statline"><span class="k">Pump</span><span class="v" id="pump">--</span></div>
            <div class="statline"><span class="k">Tank</span><span class="v" id="tank">--</span></div>
            <div class="statline"><span class="k">Raw ADC</span><span class="v" id="raw">--</span></div>
            <div class="statline"><span class="k">Auto Water</span><span class="v" id="autoState">--</span></div>
          </div>
        </div>
      </div>
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
void loop() {
  server.handleClient();
  handleManualButton();

  unsigned long now = millis();

  if (now - lastSampleMs >= SENSOR_SAMPLE_MS) {
    lastSampleMs = now;
    int pct = readMoisturePercent();

    Serial.print("Moisture: ");
    Serial.print(pct);
    Serial.print("% | Raw: ");
    Serial.print(rawReading);
    Serial.print(" | Sensor: ");
    Serial.print(moistureSensorConnected ? "OK" : "NC");
    Serial.print(" | Pump: ");
    Serial.print(pumpIsOn ? "ON" : "OFF");
    Serial.print(" | GPIO5: ");
    Serial.print(digitalRead(PUMP_PIN) == HIGH ? "HIGH" : "LOW");
    Serial.print(" | Auto: ");
    Serial.println(autoWaterEnabled ? "ON" : "OFF");

    maybeStartAutoWatering();
  }

  maybeStopPump();

  if (now - lastDisplayMs >= DISPLAY_REFRESH_MS) {
    lastDisplayMs = now;
    drawUI();
  }
}
